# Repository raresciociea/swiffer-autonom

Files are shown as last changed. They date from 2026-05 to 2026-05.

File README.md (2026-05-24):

# Robot Autonom pentru Curatenie (Swiffer Robot)

Proiect de robot autonom dezvoltat pe platforma **ATmega328P**, optimizat pentru navigare inteligenta, evadare din colturi si acoperire eficienta a spatiului fara blocaje repetitive.

## Caracteristici Tehnice & Algoritmi
* **Arhitectura 100% Non-blocanta:** Implementare bazata pe soft-timere (`millis()`), fara utilizarea functiei blocante `delay()`.
* **Masina de Stari Finita (FSM):** Gestionare curata a comportamentului prin stari dedicate (`Mers Inainte`, `Mers Inapoi`, `Rotire`, `Stop`).
* **Acoperire Organica (Memorie pe 10 Generatii):** Robotul salveaza ultimele 10 decizii intr-un vector circular. Foloseste unghiuri si timpi de viraj aleatorii (`random(400, 900)ms`) pentru a evita buclele infinite. La blocaje repetitive, declanseaza o manevra lunga de evadare (U-Turn).
* **Telemetrie Bluetooth in Timp Real:** Optimizare hardware prin scaderea timeout-ului `pulseIn()` la 3500µs pentru senzorii ultrasonici, eliminand complet lag-ul de pe modulul HC-05.
* **Citiri ADC Stabile (Fara Fluctutatii):** Tehnica *"Double Dummy Read"* pentru stabilizarea multiplexorului ADC intre senzorul de podea TCRT5000 si divizorul de tensiune al bateriei (raporteaza ~8.4V stabil).

## Componente Hardware
* **Creier:** Microcontroler ATmega328P
* **Senzori Obstacole:** 3x Senzori Ultrasonici (Fata, Stanga, Dreapta)
* **Senzor Prapastie/Margine:** 1x Senzor Infrarosu TCRT5000 (orientat spre podea)
* **Actuatori:** 2x Motoare DC conduse de o punte H **L298N**
* **Comunicare:** Modul Bluetooth **HC-05**
* **Alimentare:** Pachet baterii LiPo (2S)

## Structura Proiectului (PlatformIO)
* `src/main.cpp` — Masina de stari, algoritmul decizional, citirea senzorilor si controlul PWM al motoarelor.
* `include/hc05_comm.hpp` — Header custom dedicat pentru parsarea si curatarea bufferului serial Bluetooth.
* `platformio.ini` — Fisierul de configurare al mediului de dezvoltare.

## Ghid de Compilare si Incarcare
1. Instaleaza **VS Code** si extensia **PlatformIO IDE**.
2. Cloneaza/Deschide folderul acestui proiect in VS Code.
3. Conecteaza placuta prin cablu USB.
4. Apasa pe butonul **PlatformIO: Upload** (sageata din bara de jos) pentru compilare si scriere automata pe cip.

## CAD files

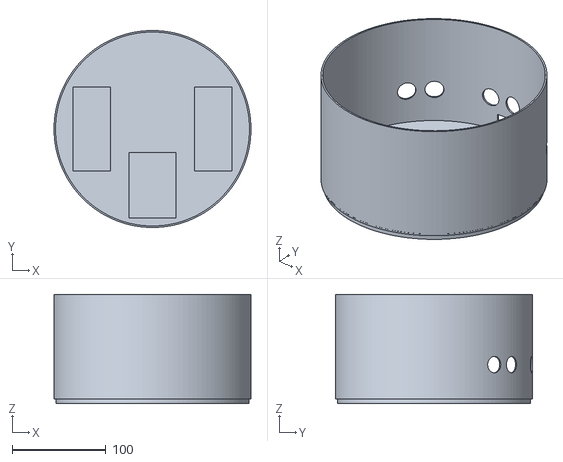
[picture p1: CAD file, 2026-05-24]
manufacturing/robot_swiffer7_thinned.stl
210.0 x 210.0 x 116.7

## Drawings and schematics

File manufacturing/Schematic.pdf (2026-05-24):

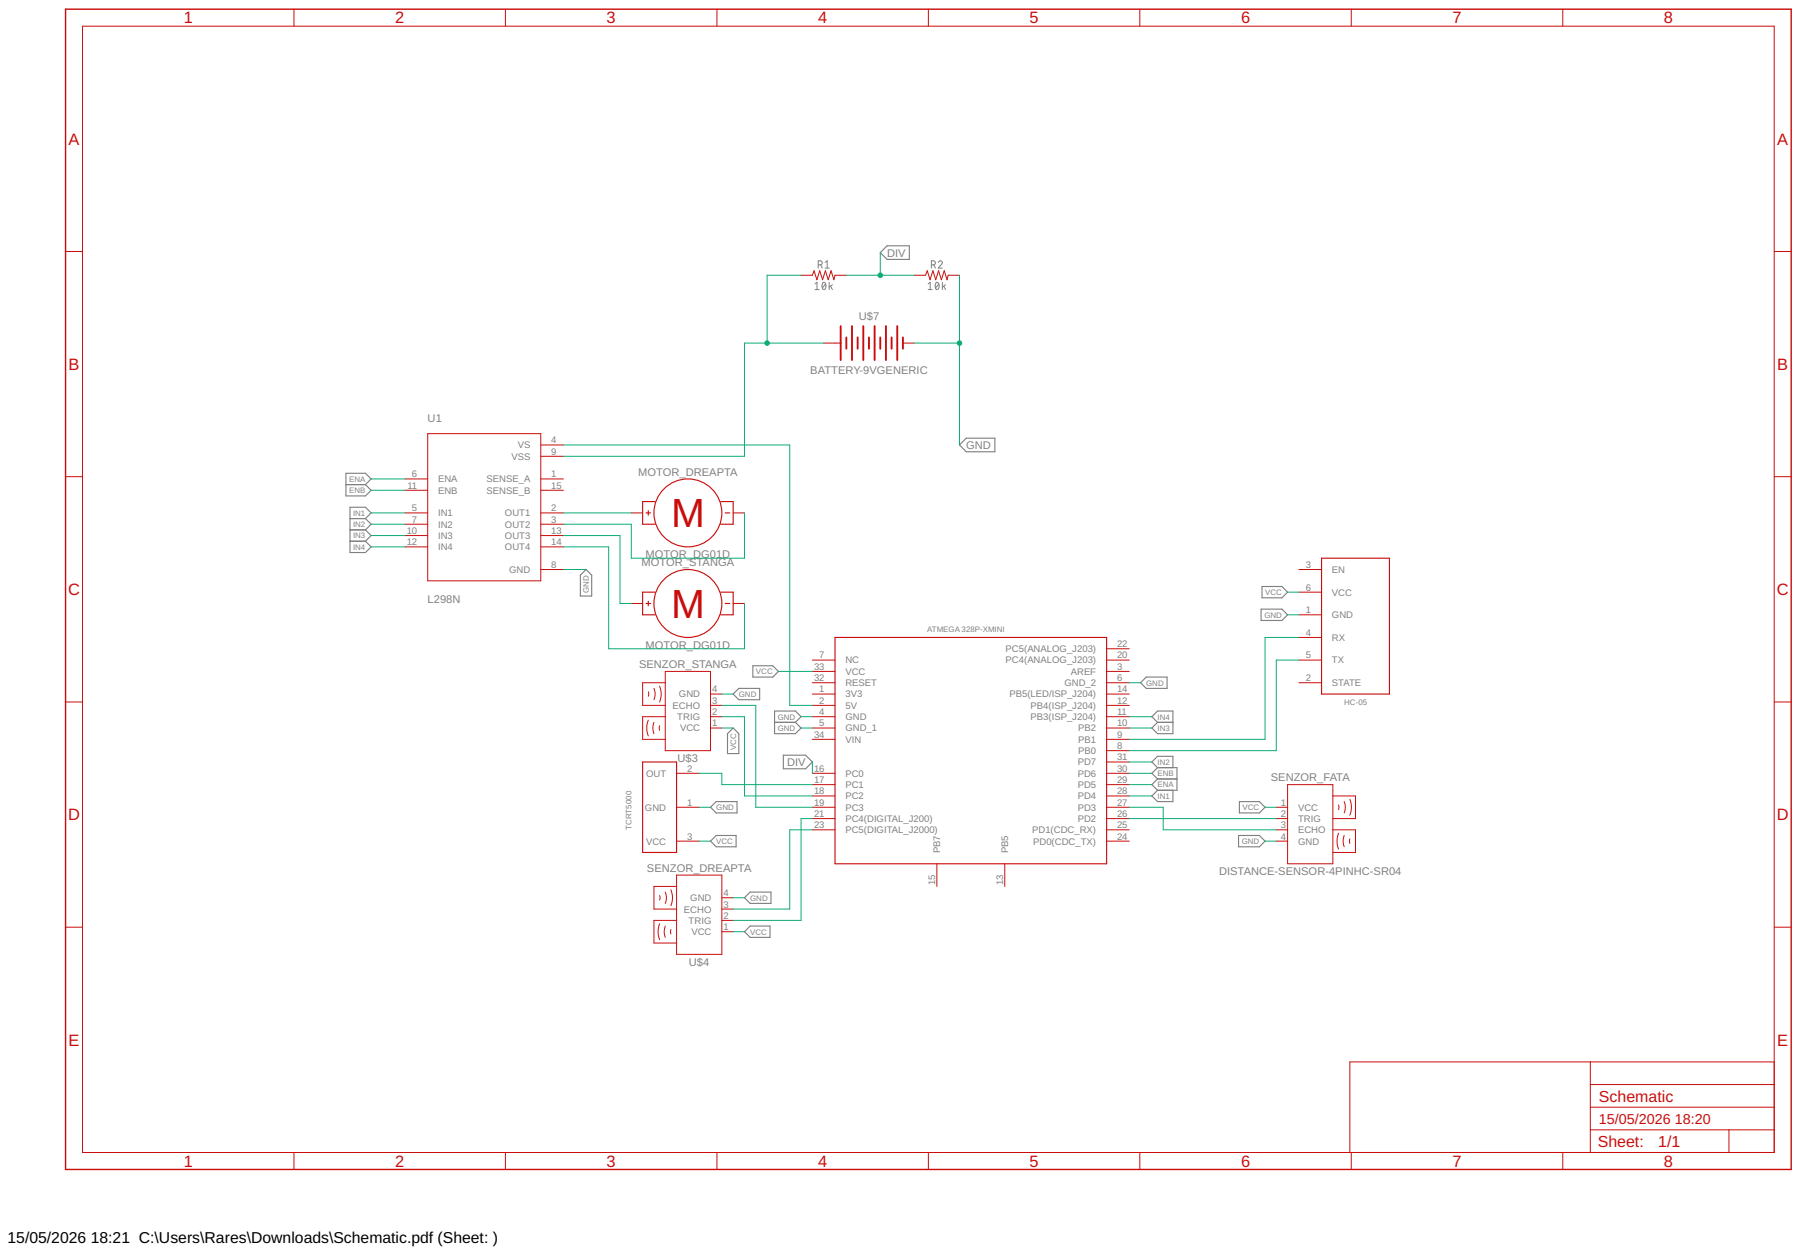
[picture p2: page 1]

GND GND

15/05/2026 18:21 C:\Users\Rares\Downloads\Schematic.pdf (Sheet: )

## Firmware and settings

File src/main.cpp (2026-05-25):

#include <Arduino.h>
#include <SoftwareSerial.h>

#include "hc05_comm.hpp"

extern SoftwareSerial BTSerial;

const int trigFata = 2;
const int echoFata = 3;
const int trigStanga = A2;
const int echoStanga = A3;
const int trigDreapta = A4;
const int echoDreapta = A5;
const int pinPodea = A1;

unsigned long ultimaTrimitereBT = 0;
const int intervalTrimitere = 1000;

#define ENA 5
#define IN1 4
#define IN2 7
#define ENB 6
#define IN3 10
#define IN4 11

int getDistanta(int trig, int echo);

int stareRobot = 0;
unsigned long timpInceputManevra = 0;
const int timpInapoi = 400;
int timpViraj = 600;

const int vitezMica = 90;
int vitezaStanga = 255;
int vitezaDreapta = 255;
int vitezaViraj = 255;

char istoricDecizii[10];
int indexIstoric = 0;
unsigned long ultimulTimpObstacol = 0;
int contorLovituriRapide = 0;
bool virajSpreStanga = false;

void salveazaDecizie(char directie) {
    istoricDecizii[indexIstoric] = directie;
    indexIstoric++;
    if (indexIstoric >= 10) {
        indexIstoric = 0;
    }
}

void opresteMotoare() {
    digitalWrite(IN1, HIGH);
    digitalWrite(IN2, HIGH);
    digitalWrite(IN3, HIGH);
    digitalWrite(IN4, HIGH);
    analogWrite(ENA, 255);
    analogWrite(ENB, 255);
    delay(50);
    digitalWrite(IN1, LOW);
    digitalWrite(IN2, LOW);
    digitalWrite(IN3, LOW);
    digitalWrite(IN4, LOW);
    analogWrite(ENA, 0);
    analogWrite(ENB, 0);
}

void pornireInForta() {
    digitalWrite(IN1, HIGH);
    digitalWrite(IN2, HIGH);
    digitalWrite(IN3, HIGH);
    digitalWrite(IN4, HIGH);
    analogWrite(ENA, 255);
    analogWrite(ENB, 255);
    delay(50);

    digitalWrite(IN1, HIGH);
    digitalWrite(IN2, LOW);
    digitalWrite(IN3, HIGH);
    digitalWrite(IN4, LOW);
    analogWrite(ENA, 230);
    analogWrite(ENB, 255);
    delay(250);
}

void mergiInainteIncet() {
    digitalWrite(IN1, HIGH);
    digitalWrite(IN2, LOW);
    digitalWrite(IN3, HIGH);
    digitalWrite(IN4, LOW);
    analogWrite(ENA, vitezaStanga);
    analogWrite(ENB, vitezaDreapta);
}

void mergiInapoiIncet() {
    digitalWrite(IN1, LOW);
    digitalWrite(IN2, HIGH);
    digitalWrite(IN3, LOW);
    digitalWrite(IN4, HIGH);
    analogWrite(ENA, vitezaViraj);
    analogWrite(ENB, vitezaViraj);
}

void rotesteStangaIncet() {
    digitalWrite(IN1, LOW);
    digitalWrite(IN2, HIGH);
    digitalWrite(IN3, HIGH);
    digitalWrite(IN4, LOW);
    analogWrite(ENA, vitezaViraj);
    analogWrite(ENB, vitezaViraj);
}

void rotesteDreaptaIncet() {
    digitalWrite(IN1, HIGH);
    digitalWrite(IN2, LOW);
    digitalWrite(IN3, LOW);
    digitalWrite(IN4, HIGH);
    analogWrite(ENA, vitezaViraj);
    analogWrite(ENB, vitezaViraj);
}

void setup() {
    Serial.begin(9600);
    BTSerial.begin(9600);

    randomSeed(analogRead(A6));

    pinMode(trigFata, OUTPUT);
    pinMode(echoFata, INPUT);
    pinMode(trigStanga, OUTPUT);
    pinMode(echoStanga, INPUT);
    pinMode(trigDreapta, OUTPUT);
    pinMode(echoDreapta, INPUT);
    pinMode(ENA, OUTPUT);
    pinMode(IN1, OUTPUT);
    pinMode(IN2, OUTPUT);
    pinMode(ENB, OUTPUT);
    pinMode(IN3, OUTPUT);
    pinMode(IN4, OUTPUT);
    pinMode(pinPodea, INPUT);

    for (int i = 0; i < 10; i++) istoricDecizii[i] = 'X';

    delay(2000);
    Serial.println("=== SISTEM MULTI-SENZOR ACTIVAT ===");
    BTSerial.println("=== ROBOT ONLINE - TOȚI SENZORII ACTIVI ===");
}

float citesteVccReal() {
    ADMUX = _BV(REFS0) | _BV(MUX3) | _BV(MUX2) | _BV(MUX1);
    delay(3);
    ADCSRA |= _BV(ADSC);
    while (bit_is_set(ADCSRA, ADSC));
    ADCSRA |= _BV(ADSC);
    while (bit_is_set(ADCSRA, ADSC));
    uint8_t low = ADCL;
    uint8_t high = ADCH;
    long result = (high << 8) | low;
    return 1125.3 / (float)result;
}

void loop() {
    int dFata = getDistanta(trigFata, echoFata);
    int dStanga = getDistanta(trigStanga, echoStanga);
    int dDreapta = getDistanta(trigDreapta, echoDreapta);
    int valPodea = analogRead(pinPodea);

    if (millis() - ultimaTrimitereBT > intervalTrimitere) {
        float riglaCurenta = citesteVccReal();
        analogRead(A0);
        delay(3);
        int valoareBruta = analogRead(A0);
        float tensiuneBaterie = valoareBruta * (riglaCurenta / 1023.0) * 2.0;

        String telemetrie = "F:" + String(dFata) + " L:" + String(dStanga) +
                            " R:" + String(dDreapta) +
                            " P:" + String(valPodea) +
                            " Bat:" + String(tensiuneBaterie, 2) + "V";

        trimiteMesaj(telemetrie);
        Serial.println(telemetrie);
        ultimaTrimitereBT = millis();
    }

    String comanda = citesteDePeTelefon();
    if (BTSerial.available() > 0) {
        String comanda = BTSerial.readStringUntil('\n');
        comanda.toLowerCase();

        if (comanda.length() > 0) {
            if (comanda.indexOf("ping") != -1) {
                BTSerial.println("PONG!");
            } else if (comanda.indexOf("start") != -1) {
                pornireInForta();
                stareRobot = 1;
                BTSerial.println("Incep modul de acoperire avansata!");
            } else if (comanda.indexOf("stop") != -1) {
                stareRobot = 0;
                opresteMotoare();
                BTSerial.println("Sistem Oprit.");
            }
        }
    }

    String mesajLpt = citesteDePeLaptop();
    if (mesajLpt.length() > 0) {
        trimiteMesaj(mesajLpt);
    }

    bool pericolPodea = (valPodea < 300);

    if (stareRobot == 1) {
        mergiInainteIncet();
        if (dFata < 30 || pericolPodea) {
            stareRobot = 2;
            timpInceputManevra = millis();

            if (millis() - ultimulTimpObstacol < 5000) {
                contorLovituriRapide++;
            } else {
                contorLovituriRapide = 0;
            }
            ultimulTimpObstacol = millis();
        }
    } else if (stareRobot == 2) {
        mergiInapoiIncet();
        if (millis() - timpInceputManevra > timpInapoi) {
            stareRobot = 3;
            timpInceputManevra = millis();

            int sCount = 0;
            int dCount = 0;
            for (int i = 0; i < 10; i++) {
                if (istoricDecizii[i] == 'S') sCount++;
                if (istoricDecizii[i] == 'D') dCount++;
            }

            if (contorLovituriRapide > 3 || sCount >= 8 || dCount >= 8) {
                virajSpreStanga = random(0, 2);
                timpViraj = random(1200, 1800);
                contorLovituriRapide = 0;
                for (int i = 0; i < 10; i++) istoricDecizii[i] = 'X';
            } else {
                if (dStanga > dDreapta + 10) {
                    virajSpreStanga = true;
                } else if (dDreapta > dStanga + 10) {
                    virajSpreStanga = false;
                } else {
                    virajSpreStanga = random(0, 2);
                }
                timpViraj = random(400, 900);
            }
            salveazaDecizie(virajSpreStanga ? 'S' : 'D');
        }
    } else if (stareRobot == 3) {
        if (virajSpreStanga) {
            rotesteStangaIncet();
        } else {
            rotesteDreaptaIncet();
        }

        if (millis() - timpInceputManevra > timpViraj) {
            pornireInForta();
            stareRobot = 1;
        }
    }
}

int getDistanta(int trig, int echo) {
    digitalWrite(trig, LOW);
    delayMicroseconds(2);
    digitalWrite(trig, HIGH);
    delayMicroseconds(10);
    digitalWrite(trig, LOW);

    long durata = pulseIn(echo, HIGH, 25000);

    if (durata == 0) return 400;

    int d = durata * 0.034 / 2;
    if (d > 400 || d < 0) return 400;

    return d;
}

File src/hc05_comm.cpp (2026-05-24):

#include "hc05_comm.hpp"

SoftwareSerial BTSerial(8, 9);

void trimiteMesaj(String text) { BTSerial.println(text); }


String citesteDePeLaptop() {
    String temp = "";
    if (Serial.available() > 0) {
        while (Serial.available() > 0) {
            char c = Serial.read();
            Serial.print(c);  

            if (c == '\n' || c == '\r') break;
            temp += c;
            delay(5);
        }
    }
    temp.trim();
    return temp;
}

String citesteDePeTelefon() {
    String temp = "";
    while (BTSerial.available() > 0) {
        char c = BTSerial.read();
        temp += c;
        delay(5);

    }
    temp.trim();
    return temp;
}

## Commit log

2026-05-24 added manufacturing
    [robot_swiffer7_thinned.stl]
2026-05-25 fixed timeout for pulse in
    [main.cpp]
